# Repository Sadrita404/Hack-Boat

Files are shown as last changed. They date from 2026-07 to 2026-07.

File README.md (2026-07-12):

<div align="center">
  <table border="0" cellpadding="0" cellspacing="0">
    <tr>
      <td align="center" style="background: #ffffff; border: 1px solid #d0d7de; border-radius: 12px; padding: 16px; box-shadow: 0 4px 12px rgba(0,0,0,0.05);">
        Rough Layout For The PCB
        <div style="margin-top: 12px; font-family: -apple-system, BlinkMacSystemFont, 'Segoe UI', Helvetica, Arial, sans-serif; font-size: 13px; color: #57606a; font-weight: 500;">
      </td>
    </tr>
  </table>
</div>

|Title | Hack Boat |
|:-- |:--|
|Author | Sadrita Neogi|

## Overview
It is an open source Hack Boat it is fully 3d Printed and it has a water cooled motor with custom rudder for boat movement it uses 6 channel transmission to control the boat also it is fully covered with carbon - fiber on the inside body

## Why I choose this project?

So behind choosing this project for a very long time, I was fascinated with this RC board since how the working principal like when I got to know about 3D printing. Then from now, I have been planning to build one for myself which I can 3-D print and it would be much more economical so for that I have made this

##  How to use this project
This project mainly is an hobby purpose project, but we can use it to feed fish or perform small rescue missions like for small project. It can send GPS tracking data from the pond with the  Attach water quality monitor to the boat and check the water Quality of the pond.

## Features
* Fully 3d Printed Body
* Water Cooled Motor
* Long Range Transmission
* Custom Water Quality Monitoring System
* Has 6 Channel transmitter
* Carbon Fiber Inside
* Fully Open Source

## General Schematic

Wiring diagram

|  |  | Building Process |  |  |
| :-: | :-: | :-: | :-: | :-: |
| Building Process 1 | Building Process 3 | Building Process 4 | Building Process 5 | Building Process 6 |
| Building Process 9 | Building Process 11 | Building Process 14 | Building Process 16 | Building Process 20 |
| Building Process 23 | Building Process 25 | Building Process 26 | Building Process 27 | Building Process 30 |
| Building Process 34 | Building Process 35 | Building Process 37 | Building Process 39 | Building Process 40 |
| Building Process 1 | Building Process 2 | Building Process 3 | Building Process 4 | Building Process 5 |  |

<div align="center">
  <h2> PCB Final (Water Quality Monitor) </h2>
  <table border="0" cellpadding="10" cellspacing="0" style="border-collapse: collapse;">
    <tr>
      <!-- FRONT SIDE CARD -->
      <td align="center" valign="top" width="50%" style="background: #ffffff; border: 1px solid #d0d7de; border-radius: 12px; padding: 16px; box-shadow: 0 4px 12px rgba(0,0,0,0.05);">
        Front Side View
        <div style="margin-top: 12px; font-family: -apple-system, BlinkMacSystemFont, 'Segoe UI', Helvetica, Arial, sans-serif; font-size: 13px; color: #57606a; font-weight: 600; text-transform: uppercase; letter-spacing: 0.5px;">
          ▲ Front Side View
        </div>
      </td>
      <!-- SPACER FOR GITHUB MOBILE DEGRADATION -->
      <td width="2%">&nbsp;</td>
      <!-- BACK SIDE CARD -->
      <td align="center" valign="top" width="50%" style="background: #ffffff; border: 1px solid #d0d7de; border-radius: 12px; padding: 16px; box-shadow: 0 4px 12px rgba(0,0,0,0.05);">
        Back Side View
        <div style="margin-top: 12px; font-family: -apple-system, BlinkMacSystemFont, 'Segoe UI', Helvetica, Arial, sans-serif; font-size: 13px; color: #57606a; font-weight: 600; text-transform: uppercase; letter-spacing: 0.5px;">
          ▲ Back Side View
        </div>
      </td>
    </tr>
  </table>
</div>
</div>

## Fusion Renders 

<div align="center">

Render 1
Render 2
Render 3
Render 4
Render 5
Render 6
Render 7

</div>

<div align="center">
  <h2> Bill of Materials</h2>
</div>

Here is your complete data formatted cleanly as a Markdown table, matching your requested format exactly:

| Name | Purpose | Quantity | Total Cost (USD) | Link | Distributor |
| --- | --- | --- | --- | --- | --- |
| Rocket 3670 brushless rc boat motor | The Main Motor | 1 | 36 | [Link](https://robu.in/product/rocket-3670-brushless-rc-boat-motor-4pole-%ef%bf%a05-0mm-black-1550-kv/) | Robu |
| Water Cooling Jacket for RC Boat Brushless Motor | To cool the motor from overheating | 1 | 13 | [Link](https://www.amazon.in/MERISHOPP-2xMetal-Brushless-Educational-Learning/dp/B0FQCK9XJG) | Amazon |
| 80A Bidirectional Water-Cooled ESC 2-6S | To run the Motor | 1 | 28 | [Link](https://evelta.com/50a-60a-80a-bidirectional-water-cooled-esc-2-6s-ubec-5a-5v-for-rc-ship-underwater-propeller/?sku=447-E-125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) | Evelta |
| RC Boat Rudder with Absoring Water Pickup | For the Boat Movement | 1 | 13 | [Link](https://www.amazon.in/SNAPPSY%C2%AE-Control-Absoring-Vehicle-Accessories/dp/B0GF7ZSJV9) | Amazon |
| RC Ship Drive Shaft+Motor Coupler | For the Boat Movement | 1 | 17 | [Link](https://www.amazon.in/Enakshi%C2%AE-Coupler-Propeller-Hobbies-Vehicle/dp/B0FR44DW2N) | Amazon |
| RC Boat Flex Shaft Prop | For the Boat Movement | 1 | 20 | [Link](https://www.amazon.in/ZDingTech-UDI005-09-UDI005-Upgrade-Propellers/dp/B0CDL9DS27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) | Amazon |
| Pro- Range 22.2V 4200mAh 35C 6S Lithium Polymer Battery | To power the whole circuit(this need for the motor to run at least for 15mins) | 1 | 59.2 | [Link](https://robu.in/product/orange-4200mah-6s-40c80c-lithium-polymer-battery-pack-lipo/) | Robu |
| Digital Waterproof 20KG 270 Degree DC Servo | For Rudder Movement | 1 | 22 | [Link](https://robu.in/product/digital-waterproof-20kg-270-degree-dc-servo/) | Robu |
| IMAX B6 80W 6A Charger/Discharger | To charge the battery | 1 | 19.1 | [Link](https://robu.in/product/imax-b6-80w-6a-charger-discharger-1-6-cells/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) | Robu |
| CT-8A Transmitter+F-08A Receiver(PWM) | To Control the boat | 1 | 34 | [Link](https://robu.in/product/ct-8a-transmitterf-08a-receiverpwm/) | Robu |
| Silicon Carbide Scratch Filler Putty Grey | To hide the layer lines of the 3d Print and to make the surface smooth | 1 | 3 | [Link](https://www.amazon.in/VAI-Silicon-Carbide-Sandpaper-Scratches/dp/B0DRT95YYG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) | Amazon |
| Epoxy Resin and Hardener | To make the boat water proof | 1 | 2.99 | [Link](https://www.amazon.in/DYNAMIC-EDGE-Hardener-Long-Lasting-Non-Toxic/dp/B0CWZ8G5CM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) | Amazon |
| Carbon Fiber Fabric 30x100cm | To make the frame strong | 1 | 10.5 | [Link](https://www.amazon.in/carbonblack-composites-genuine-carbon-fabric/dp/B07QF46HPG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) | Amazon |
| Clear Coat | To make the paint stay at the body | 1 | 2.2 | [Link](https://www.amazon.in/Nippon-Paint-Pylac-Spray-RS-Clear/dp/B01GKBXW2A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) | Amazon |
| Spray Paint Colour | For the boat | 1 | 2.2 | [Link](https://www.amazon.in/Asian-Paints-ezyCR8-Apcolite-Spray/dp/B0FK4SN4KF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) | Amazon |
| PCB(moq5)| For the water quality Monitor | 5 | 4| [JLCPCB](https://jlcpcb.com/)| JLCPCB |
| Tax |  |  | 3.3 |  |  |
| Shipping Charges | incl PCB |  | 14.2 |  |  |
| Total |  |  | 303 |  |  |
| Round Off Total | Dollar rate fluctuation |  | 310 |  |  |

## Copyright and License
Copyright (c) 2026 Sadrita Neogi. All rights reserved.

All files are licensed under the MIT license. For more information, see the [LICENSE](LICENSE).

Project Under Hack Club

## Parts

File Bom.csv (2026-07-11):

Name | Purpose | Quantity | Total Cost (USD) | Link | Distributor
Rocket 3670 brushless rc boat motor | The Main Motor | 1 | 36 | https://robu.in/product/rocket-3670-brushless-rc-boat-motor-4pole-%ef%bf%a05-0mm-black-1550-kv/ | Robu
Water Cooling Jacket for RC Boat Brushless Motor | To cool the motor from overheating | 1 | 13 | https://www.amazon.in/MERISHOPP-2xMetal-Brushless-Educational-Learning/dp/B0FQCK9XJG | Amazon
80A Bidirectional Water-Cooled ESC 2-6S | To run the Motor | 1 | 28 | https://evelta.com/50a-60a-80a-bidirectional-water-cooled-esc-2-6s-ubec-5a-5v-for-rc-ship-underwater-propeller/?sku=447-E-125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 | Evelta
RC Boat Rudder with Absoring Water Pickup | For the Boat Movement | 1 | 13 | https://www.amazon.in/SNAPPSY%C2%AE-Control-Absoring-Vehicle-Accessories/dp/B0GF7ZSJV9 | Amazon
RC Ship Drive Shaft+Motor Coupler | For the Boat Movement | 1 | 17 | https://www.amazon.in/Enakshi%C2%AE-Coupler-Propeller-Hobbies-Vehicle/dp/B0FR44DW2N | Amazon
RC Boat Flex Shaft Prop | For the Boat Movement | 1 | 20 | https://www.amazon.in/ZDingTech-UDI005-09-UDI005-Upgrade-Propellers/dp/B0CDL9DS27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 | Amazon
Pro- Range 22.2V 4200mAh 35C 6S Lithium Polymer Battery | To power the whole circuit | 1 | 59.2 | https://robu.in/product/orange-4200mah-6s-40c80c-lithium-polymer-battery-pack-lipo/ | Robu
Digital Waterproof 20KG 270 Degree DC Servo | For Rudder Movement | 1 | 22 | https://robu.in/product/digital-waterproof-20kg-270-degree-dc-servo/ | Robu
IMAX B6 80W 6A Charger/Discharger | To charge the battery | 1 | 19.1 | https://robu.in/product/imax-b6-80w-6a-charger-discharger-1-6-cells/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 | Robu
CT-8A Transmitter+F-08A Receiver(PWM) | To Control the boat | 1 | 34 | https://robu.in/product/ct-8a-transmitterf-08a-receiverpwm/ | Robu
Silicon Carbide Scratch Filler Putty Grey | To hide the layer lines of the 3d Print and to make the surface smooth | 1 | 3 | https://www.amazon.in/VAI-Silicon-Carbide-Sandpaper-Scratches/dp/B0DRT95YYG?adgrpid=198415552724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 | Amazon
Epoxy Resin and Hardener | To make the boat water proof | 1 | 2.99 | https://www.amazon.in/DYNAMIC-EDGE-Hardener-Long-Lasting-Non-Toxic/dp/B0CWZ8G5CM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 | Amazon
Carbon Fiber Fabric 30x100cm | To make the frame strong | 1 | 10.5 | https://www.amazon.in/carbonblack-composites-genuine-carbon-fabric/dp/B07QF46HPG | Amazon
Clear Coat | To make the paint stay at the body | 1 | 2.2 | https://www.amazon.in/Nippon-Paint-Pylac-Spray-RS-Clear/dp/B01GKBXW2A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 | Amazon
Spray Paint Colour | For the boat | 1 | 2.2 | https://www.amazon.in/Asian-Paints-ezyCR8-Apcolite-Spray/dp/B0FK4SN4KF?mcid=e4589ed26a5734c9afb790c57e249174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 | Amazon
PCB(moq5) | For the water quality monitor | 5 | 4 | https://jlcpcb.com/ | JLCPCB
Tax |  |  | 3.3
Shipping Charges | Incl. PCB |  | 14.2
Total |  |  | 303
Round Off Total | Dollar rate fluctuation | 310

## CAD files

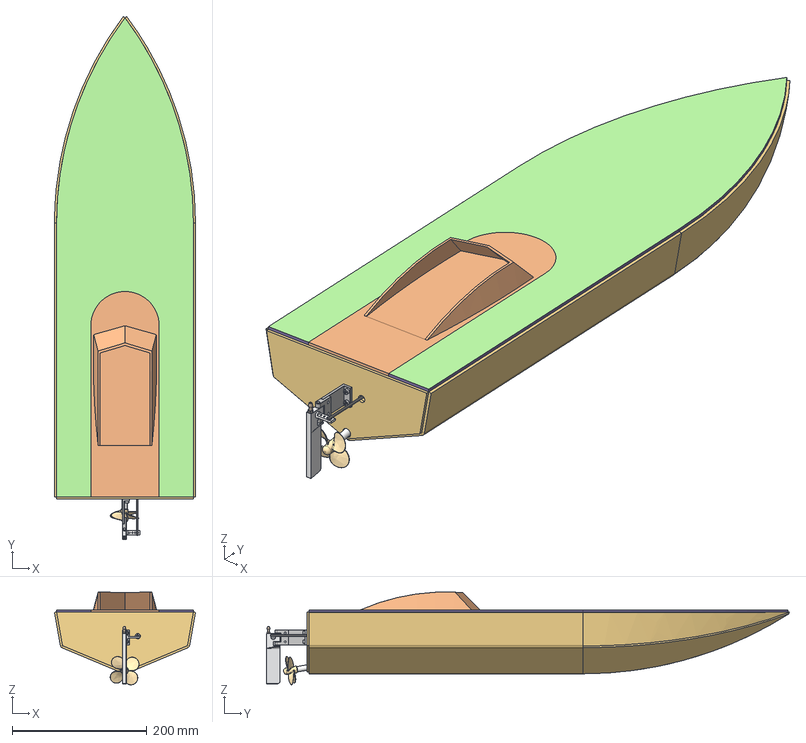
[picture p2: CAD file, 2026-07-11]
CAD/Hack Boat Assembly.step
209.5 x 776.4 x 137.7 mm
BateauVinh
PlancherBateauVinh
CokpitBateauVinh
BateauVinhPlateMotor
BateauVinhServoPlate
BS EN ISO 4762 - M3 x 16 Stainless Steel A4 Plain x 2
10000003170_000_SWP
10000003171_000_SWP
10000003172_000_SWP
100000116333_000_SWP_01
100000116172_000_SWP_5
10000011598_000_SWP
100000116172_000_SWP_4
100000115689_000_SWP

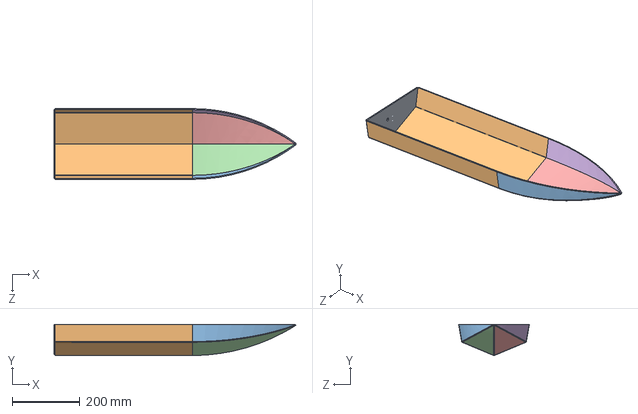
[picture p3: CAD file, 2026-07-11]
CAD/Base Case.STEP
716.3 x 92.0 x 209.5 mm

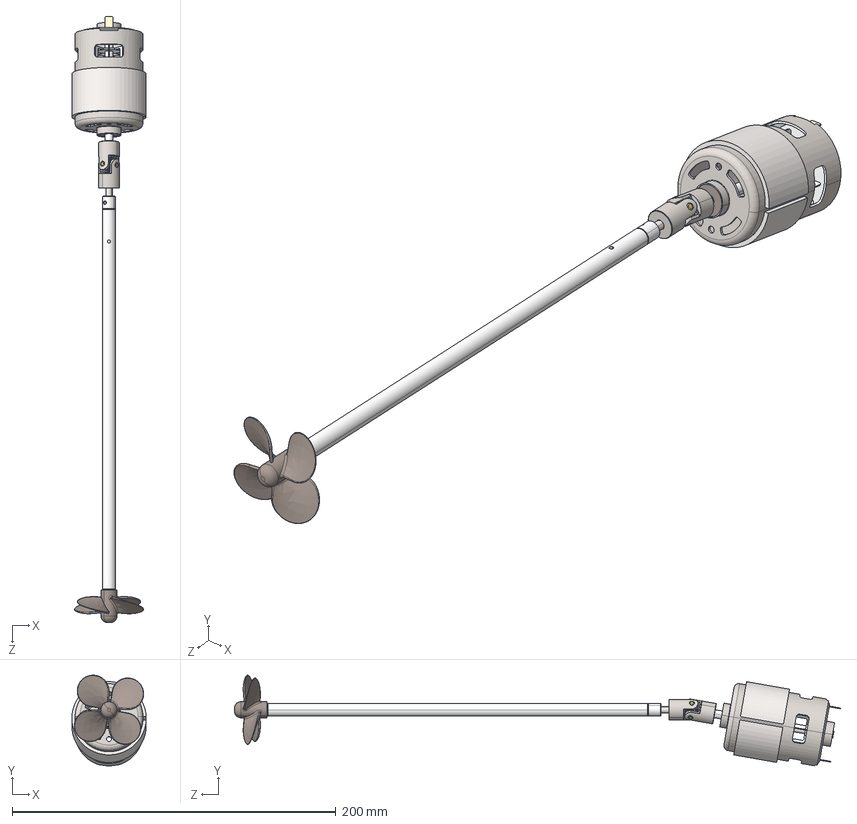
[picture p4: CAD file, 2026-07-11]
CAD/Propeller.STEP
46.0 x 56.1 x 374.6 mm
10000003170_000_SWP
10000003171_000_SWP
10000003172_000_SWP
100000116333_000_SWP_01
100000116172_000_SWP_�5
10000011598_000_SWP
100000116172_000_SWP_�4
100000115689_000_SWP

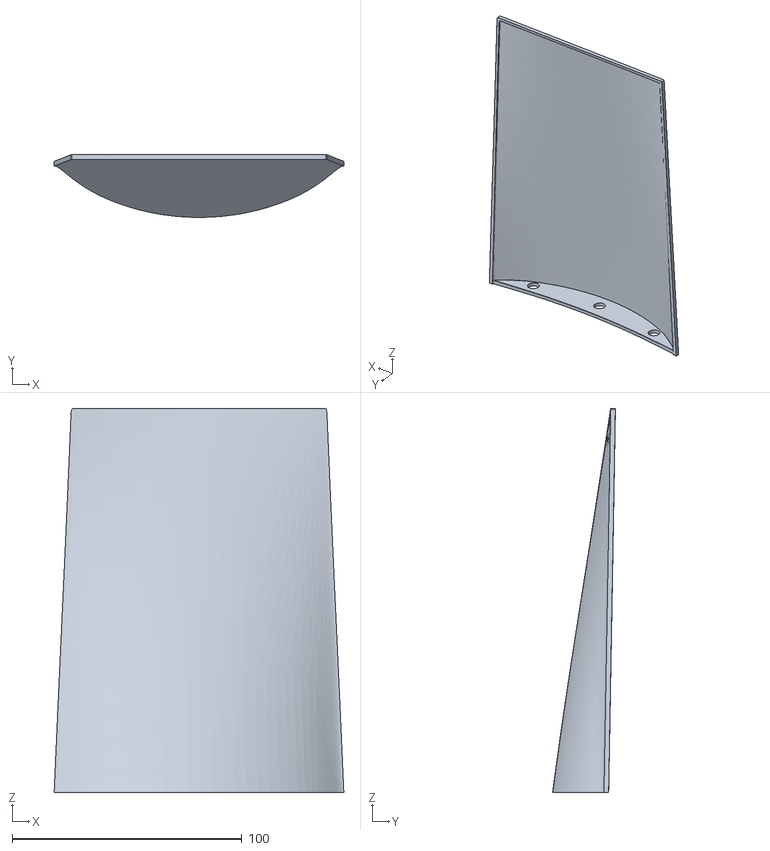
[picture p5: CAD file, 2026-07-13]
Hack Boat STL/[x1]case.stl
126.0 x 27.4 x 167.1

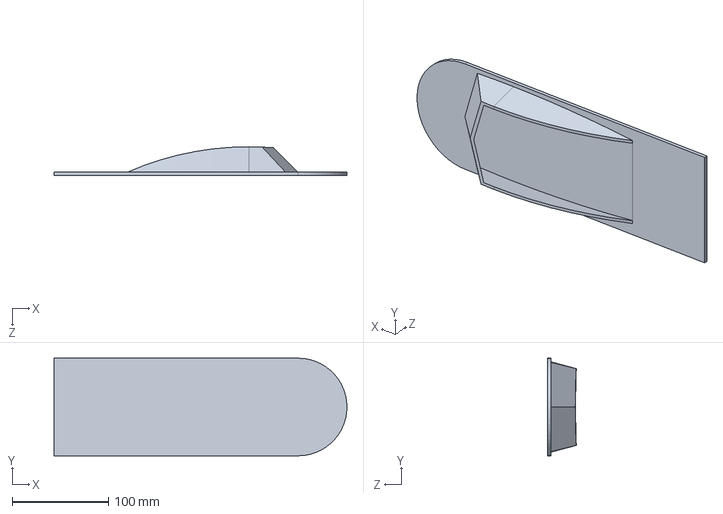
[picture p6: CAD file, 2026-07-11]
CAD/Top Cokpit Case.STEP
304.8 x 101.6 x 29.6 mm

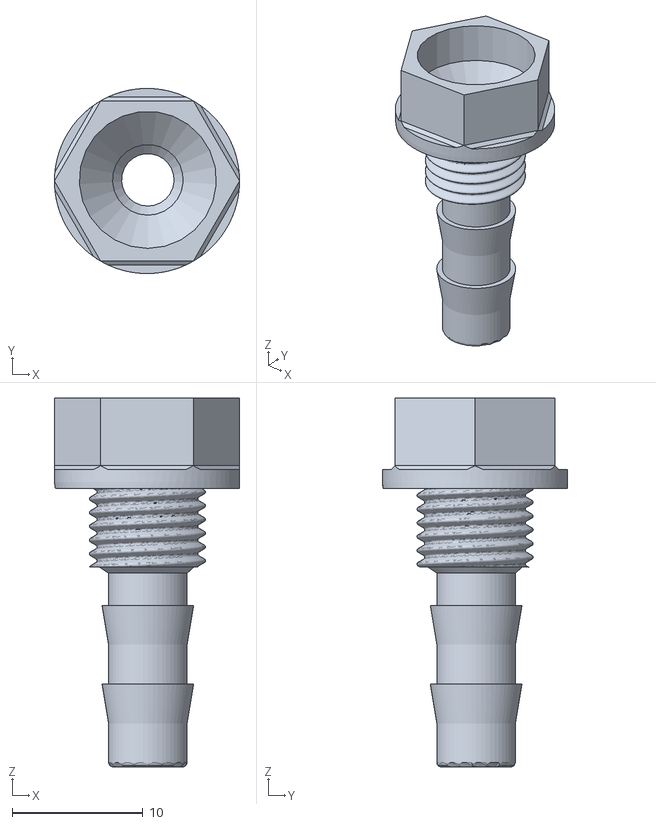
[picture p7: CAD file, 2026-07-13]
Hack Boat STL/[x2]Nozzle-6mm.stl
14.1 x 14.1 x 28.2

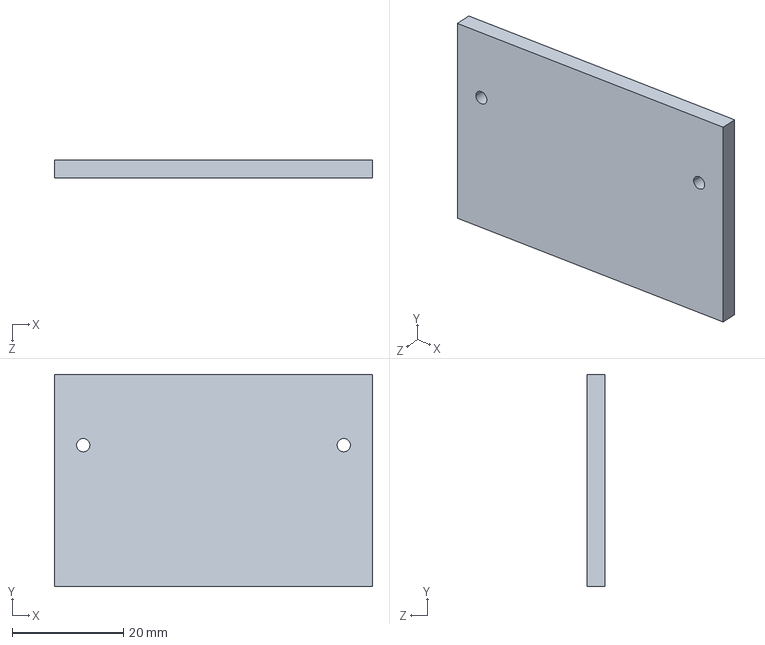
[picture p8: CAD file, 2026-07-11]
CAD/Servo mount Plate.STEP
57.1 x 38.1 x 3.17 mm

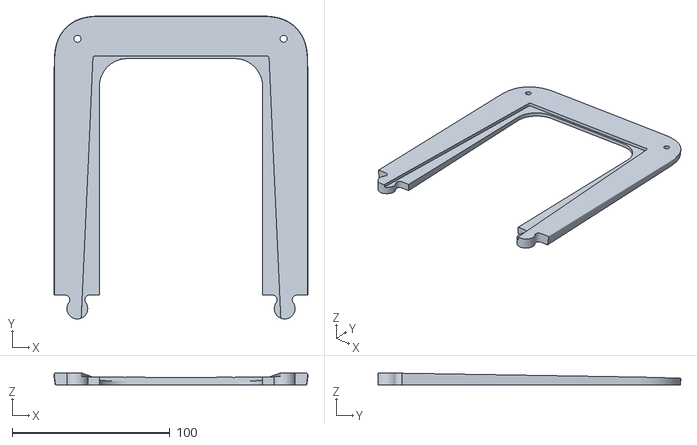
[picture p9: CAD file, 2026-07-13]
Hack Boat STL/[x1]lid top plate.stl
160.5 x 191.8 x 7.81

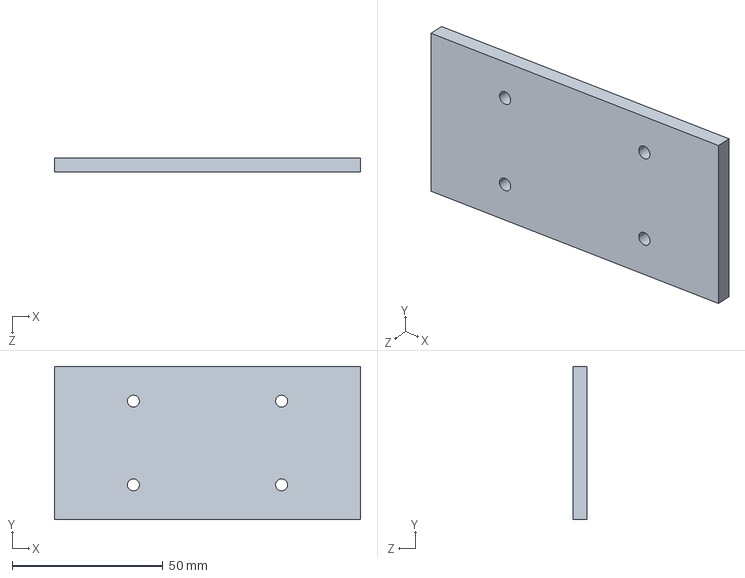
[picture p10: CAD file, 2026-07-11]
CAD/Motor mount Plate.STEP
101.6 x 50.8 x 4.76 mm

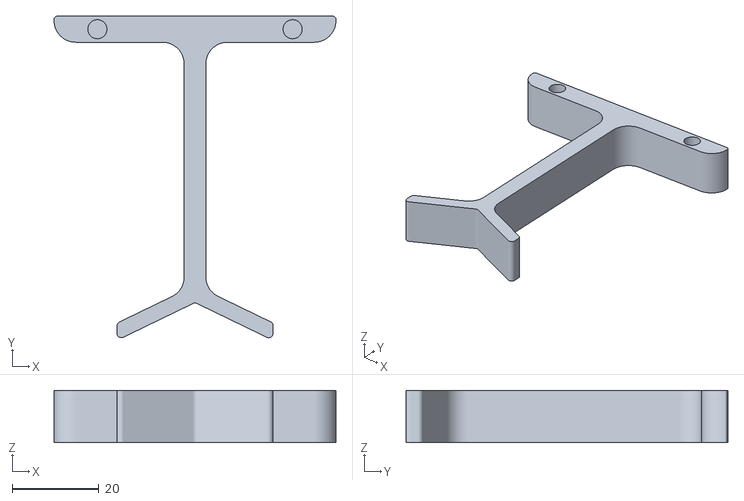
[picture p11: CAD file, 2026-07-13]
Hack Boat STL/[x2]stand.stl
65.0 x 74.1 x 12.0

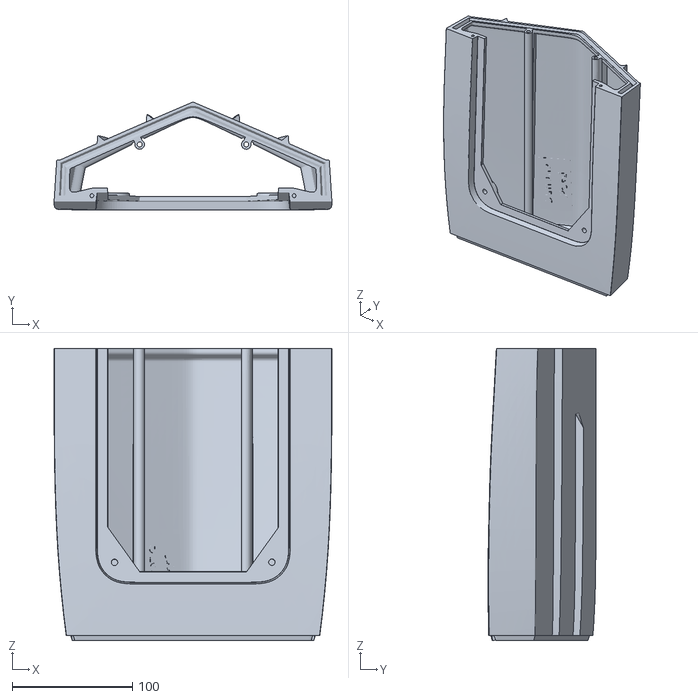
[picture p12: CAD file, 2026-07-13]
Hack Boat STL/[x1]bottom.stl
230.9 x 89.8 x 242.8

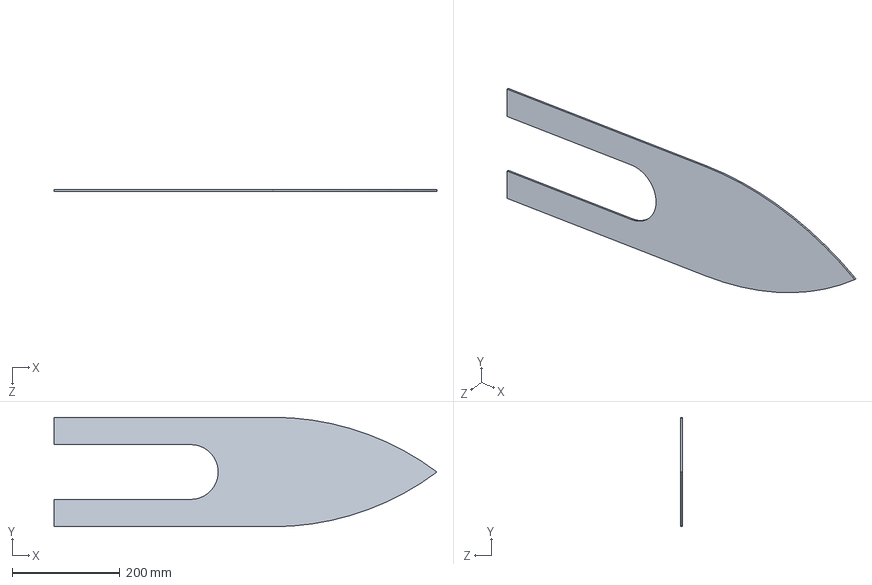
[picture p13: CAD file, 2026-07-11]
CAD/Top Cokpit Plate.STEP
711.2 x 203.2 x 3.17 mm

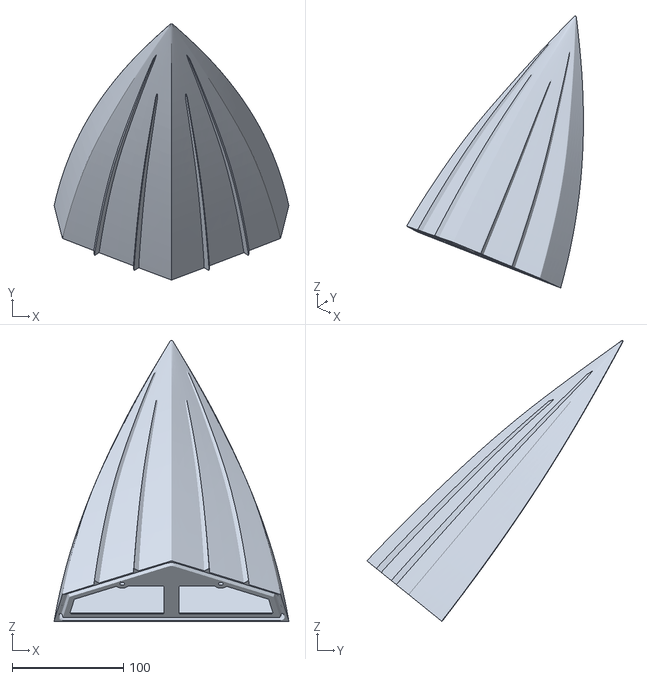
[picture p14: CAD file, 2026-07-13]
Hack Boat STL/[x1]nose.stl
210.9 x 230.1 x 252.4

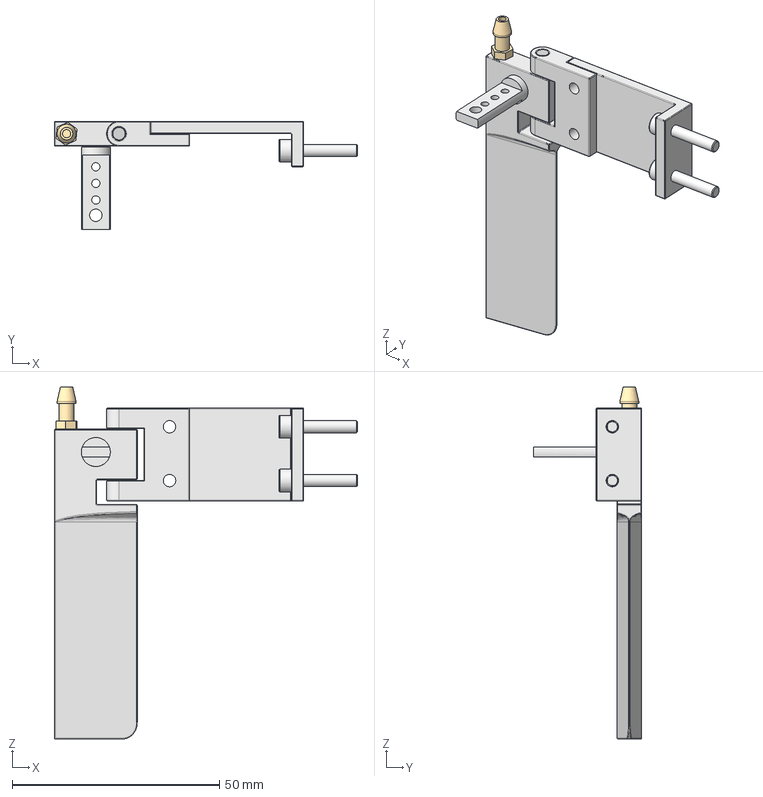
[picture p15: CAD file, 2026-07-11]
CAD/Boat Rudder.step
73.2 x 26.2 x 85.0 mm
BS EN ISO 4762 - M3 x 16 Stainless Steel A4 Plain x 2

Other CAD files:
Hack Boat STL/[x1]back chamber.stl
Hack Boat STL/[x1]top coover.stl
Hack Boat STL/[x1]lid.stl
Hack Boat STL/[x2]nozzle-screw.stl

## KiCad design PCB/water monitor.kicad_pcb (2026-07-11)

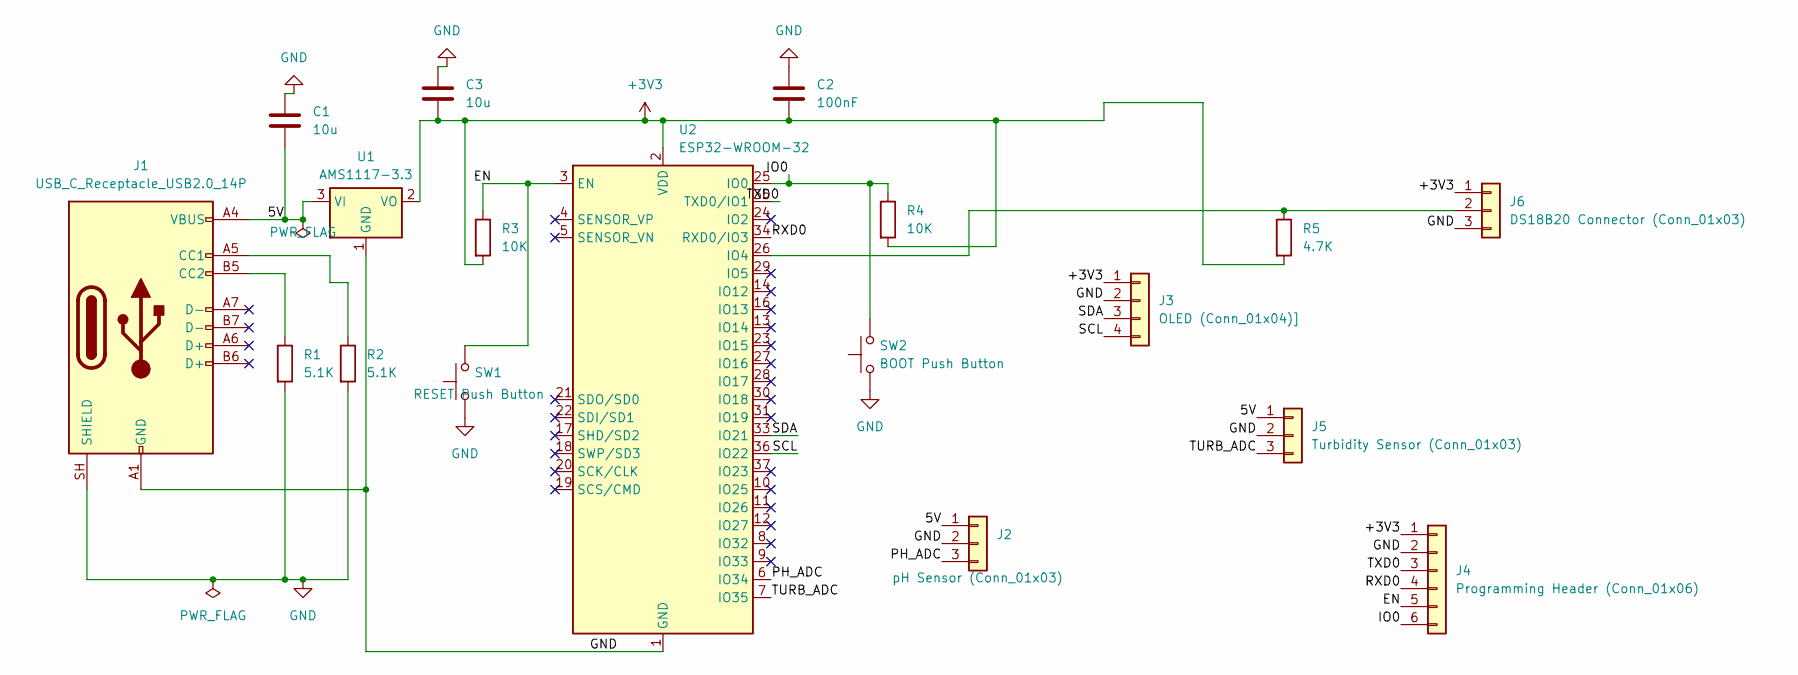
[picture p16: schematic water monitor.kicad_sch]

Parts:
C1, C3: 10u; C_0805_2012Metric
C2: 100nF; C_0805_2012Metric
J1: USB_C_Receptacle_USB2.0_14P; USB_C_Receptacle_GCT_USB4105-xx-A_16P_TopMnt_Horizontal
J2: pH Sensor (Conn_01x03); PinHeader_1x03_P2.54mm_Vertical
J3: OLED (Conn_01x04)]; PinHeader_1x04_P2.54mm_Vertical
J4: Programming Header (Conn_01x06); PinHeader_1x06_P2.54mm_Vertical
J5: Turbidity Sensor (Conn_01x03); PinHeader_1x03_P2.54mm_Vertical
J6: DS18B20 Connector (Conn_01x03); PinHeader_1x03_P2.54mm_Vertical
R1, R2: 5.1K; R_0805_2012Metric
R3, R4: 10K; R_0805_2012Metric
R5: 4.7K; R_0805_2012Metric
SW1: RESET Push Button; SW_PUSH_6mm
SW2: BOOT Push Button; SW_PUSH_6mm
U1: AMS1117-3.3; SOT-223-3_TabPin2
U2: ESP32-WROOM-32

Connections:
+3V3: C2.2, C3.2, J3.1, J4.1, J6.1, R3.2, R4.2, R5.2, U1.2 (VO), U2.2 (VDD)
/5V: C1.2, J1.A4 (VBUS), J1.A9 (VBUS), J1.B4 (VBUS), J1.B9 (VBUS), J2.1, J5.1, U1.3 (VI)
/EN: J4.5, R3.1, SW1.2, U2.3 (EN)
/IO0: J4.6, R4.1, SW2.2, U2.25 (IO0)
/PH_ADC: J2.3, U2.6 (IO34)
/RXD0: J4.4, U2.34 (RXD0/IO3)
/SCL: J3.4, U2.36 (IO22)
/SDA: J3.3, U2.33 (IO21)
/TURB_ADC: J5.3, U2.7 (IO35)
/TXD0: J4.3, U2.35 (TXD0/IO1)
GND: C1.1, C2.1, C3.1, J1.A1 (GND), J1.A12 (GND), J1.B1 (GND), J1.B12 (GND), J1.SH (SHIELD), J2.2, J3.2, J4.2, J5.2, J6.3, R1.2, R2.2, SW1.1, SW2.1, U1.1 (GND), U2.1 (GND), U2.15 (GND), U2.38 (GND), U2.39 (GND)
unnamed: J1.A5 (CC1), R2.1
unnamed: J1.B5 (CC2), R1.1
unnamed: J6.2, R5.1, U2.26 (IO4)

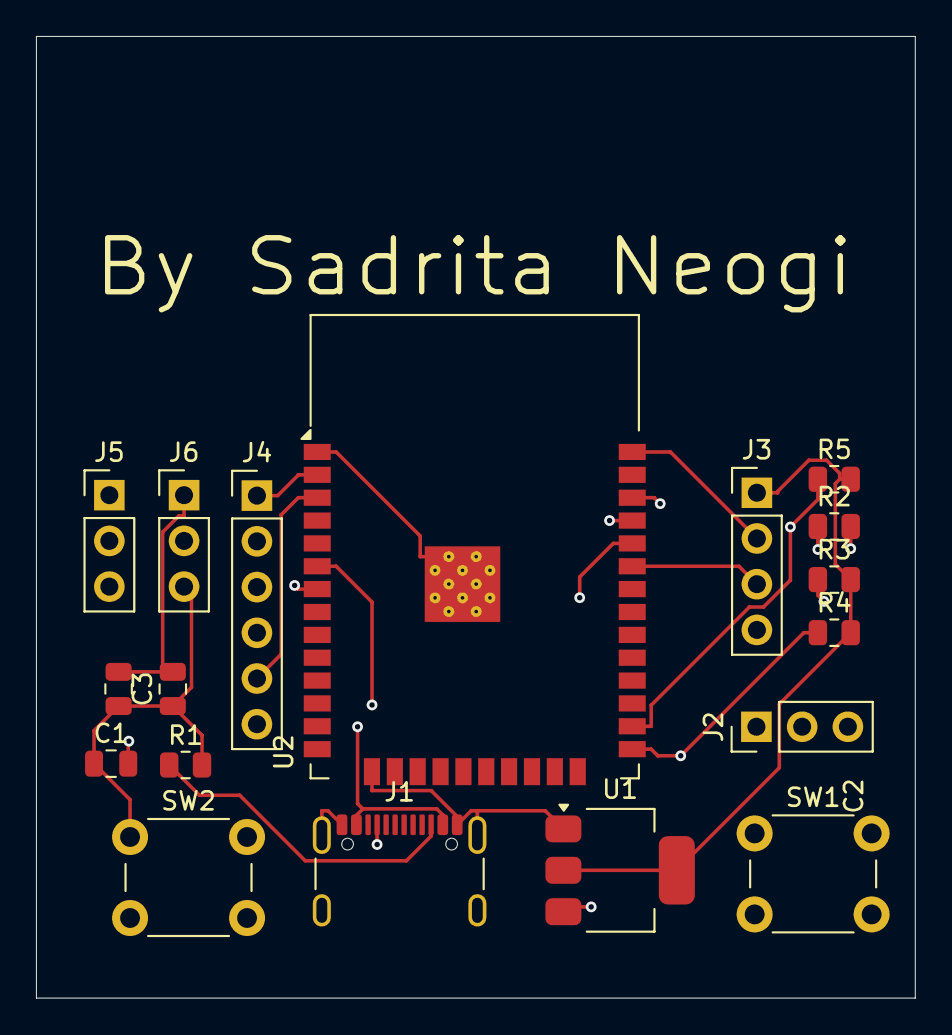
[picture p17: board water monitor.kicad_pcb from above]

Board: 4 copper layers, 48.8 x 53.4 mm, 18 parts (0 on the bottom side), 14 nets.

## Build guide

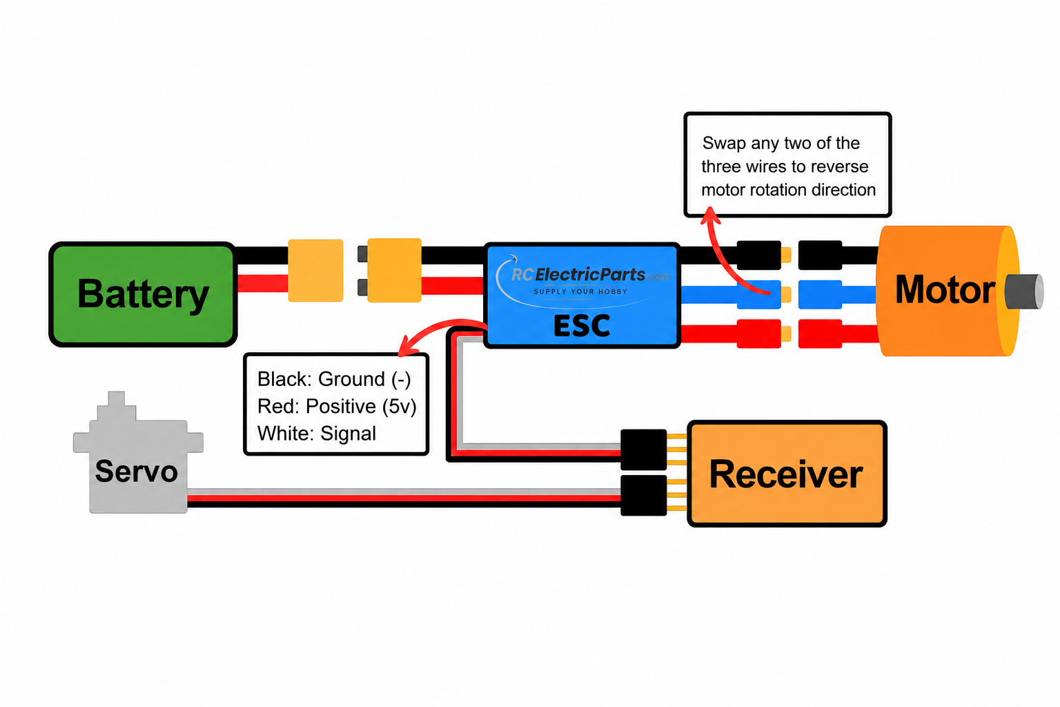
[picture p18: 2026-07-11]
Wiring Diagram/Wiring diagram.png

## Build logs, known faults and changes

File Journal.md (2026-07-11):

| Title | Hack Boat|
| :-- | :---|
|Author |Sadrita Neogi|
|Type | Hardware  |
Total Hrs | 18.1  |

# research about RC Boat and its design structure
So after deciding the project that I will build an RC boat, I went online to search for design model or the measurement dimension that I need to keep in mind while building it, so I dip into it and found out some key features that I need to think before making the CAD model..







_Total Time = 2hrs_

---
# Starting With the CAD

So after getting the design idea and the dimension, I wrote it down on a notebook. Then I started doing the cat mode according to the reference that I took from online and the inspo with it.
So for the first, I designed the top lid of the case for the base structure from where I can make the measurement changes so that I can now move onto the bottom part.




_Total Time = 0.6hrs_

---

# Making the nose of the boat 

So now, after completing with the top part of the boat, now from there, I took the measurement of the font, nose Path, and I am making one Way nose design and I have started making th CAD model for that I want to make it 3d Printable For that reason I am making into part wise .

**Inspo**





This took me lot of time as I was not familiar with this kind of design, so I need to watch a little bit tutorial and search online about how to design this kind of type side panel

_Total Time = 3.3hrs_

---

# Making the full Case

So After making the the front Nose of the Boat I went to add the top lid and the bottom part at one place so that I can make it together and move to the next part 




_Total Time = 0.4hrs_

---

# Maing the Rc Boat propeller with Motor and the connector 

Now I am working on the Rc Boat propeller for the boat which will be added with the motor and I have design mine for this as I am custom builiding it and no cad model is avilable for this build so I went to desing it bymy own and I keep the design simple but with correct dimensions .

**Making the axial Rod**






**Now the Coupler for the axial Rod and the Motor**






_Total Time = 2.2hrs_

---

# Now adding the Motor to the Boat (But not complete)

So after designing the Motor with the propeller Now I went to add that Model to the main assembly file of the project 





**While adding the motor to the boat, I found out that I need to 1st add the rudder to the model so that I can get the clearance to add the motor after that, so now I will make the rudder for the boat. Then I will add the motor.**

_Total Time = 0.2hrs_

---

# Making the Rudder for the Boat 

After I found out the problem, that first I need to made the Rudder for the Boat so now I am makign the Rudder for the boat in fusion 360 so that I can add it to the boat an next I can move to add the motor to it . and for the Rudder I made the tail custom for this boat ..










_Total Time = 2hrs_

---

# Now adding the  Rudder to the Boat 

After making the Rudder for the Boat now I move to add this to the main boat frame so that I can next add the motor and the propeller to it 






_Total Time = 0.4hrs_

---

# Now adding the Motor to the Boat (Final) and the servo shaft

 So now I have added the rider in the back of the boat. Now I can get the right dimension so that I can work on the motor and the propeller, and I have added it to the final assembly.





**servo shaft making**





_Total Time = 1.3hrs_

---

# Adding appearance to the final model






**Adding good metal texture to the rudder for the Render**



**Went for Hack Club Logo to add it in the Boat**


flag-standalone-bw

**adding the Hacl Club Logo to the Boat**




_Total Time = 1.1hrs_

# Making the Water Quality checker 

So my initial plan was to get an premade product, but later I found out then the custom bill was incomplete for that's why design and small. Simple water quality check so that I can put it into the boat and for that I have designed this and I have also made it using USB type C port for better connectivity

**First, I done with the schematic**

Screenshot 2026-07-12 at 2 38 53 AM

Screenshot 2026-07-12 at 2 39 08 AM

Screenshot 2026-07-12 at 2 39 27 AM

Screenshot 2026-07-12 at 2 39 32 AM

## DRC Check No error

Screenshot 2026-07-12 at 2 42 13 AM

Screenshot 2026-07-12 at 2 40 58 AM

Screenshot 2026-07-12 at 2 41 13 AM

_Total Time = 3.3hrs_

---

# Final Render in Fusion 360 

I actually like the final Render hopefully everyone also likes it ..
And it took a lot of time in the render as I need to creat the environment for each indiidual for each render and also it take a while to reender all the images.

Render 1
Render 2
Render 7

Render 3
Render 6

Render 4
Render 5

_Total Time = 1.3hrs_

---

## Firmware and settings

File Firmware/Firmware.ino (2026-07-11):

#include <Arduino.h>
#include <WiFi.h>
#include <AsyncTCP.h>
#include <ESPAsyncWebServer.h>
#include <Preferences.h>
#include <ArduinoJson.h>
#include <OneWire.h>
#include <DallasTemperature.h>


// --- Network Settings ---
const char* AP_SSID = "Pond-Water-Monitor-Pro";
const char* AP_PASS = "pond123456";
const char* ST_SSID = "YOUR_WIFI";      // Change to your home WiFi SSID if needed
const char* ST_PASS = "YOUR_PASSWORD";  // Change to your home WiFi Password

// --- Core Architecture Definitions ---
AsyncWebServer server(80);
AsyncWebSocket ws("/ws");
Preferences preferences;
OneWire oneWire(ONE_WIRE_BUS);
DallasTemperature sensors(&oneWire);

// FreeRTOS Task Handles
TaskHandle_t SensorTaskHandle = NULL;
TaskHandle_t TelemetryTaskHandle = NULL;
SemaphoreHandle_t dataMutex;

// --- Data Structures ---
struct WaterMetrics {
    float temperature = 25.0;
    float ph = 7.0;
    float tds = 0.0;
    float turbidity = 0.0;
    unsigned long timestamp = 0;
};

struct CalibrationData {
    float ph_4_voltage;
    float ph_7_voltage;
    float tds_factor;
    float turbidity_offset;
    float temp_offset;
};

// Global Context Instantiations
WaterMetrics currentMetrics;
CalibrationData calibration;
bool isSystemCalibrated = false;

// --- Signal Conditioning & Filtering ---
// Sorts samples and calculates the average of the middle variance band to eliminate spike noise
float readFilteredAnalog(uint8_t pin, int totalSamples = 32) {
    int samples[totalSamples];
    
    // Acquire samples
    for (int i = 0; i < totalSamples; i++) {
        samples[i] = analogRead(pin);
        delayMicroseconds(80);
    }
    
    // Simple bubble sort
    for (int i = 0; i < totalSamples - 1; i++) {
        for (int j = i + 1; j < totalSamples; j++) {
            if (samples[i] > samples[j]) {
                int temp = samples[i];
                samples[i] = samples[j];
                samples[j] = temp;
            }
        }
    }
    
    // Discard upper and lower 25% of samples, average the middle 50%
    long sum = 0;
    int startSample = totalSamples / 4;
    int endSample = totalSamples - startSample;
    int sampleCount = endSample - startSample;
    
    for (int i = startSample; i < endSample; i++) {
        sum += samples[i];
    }
    
    return (float)sum / sampleCount;
}

// --- Non-Volatile Memory (NVM) Management ---
void loadCalibrationSettings() {
    preferences.begin("pond_cal_v2", false);
    calibration.ph_4_voltage = preferences.getFloat("ph4v", 3.05);
    calibration.ph_7_voltage = preferences.getFloat("ph7v", 2.50);
    calibration.tds_factor = preferences.getFloat("tdsf", 1.00);
    calibration.turbidity_offset = preferences.getFloat("turboff", 0.0);
    calibration.temp_offset = preferences.getFloat("tempoff", 0.0);
    isSystemCalibrated = preferences.getBool("is_cal", false);
    preferences.end();
    Serial.println("[SYSTEM] Calibration settings loaded successfully from NVM.");
}

void saveCalibrationSettings() {
    preferences.begin("pond_cal_v2", false);
    preferences.putFloat("ph4v", calibration.ph_4_voltage);
    preferences.putFloat("ph7v", calibration.ph_7_voltage);
    preferences.putFloat("tdsf", calibration.tds_factor);
    preferences.putFloat("turboff", calibration.turbidity_offset);
    preferences.putFloat("tempoff", calibration.temp_offset);
    preferences.putBool("is_cal", true);
    preferences.end();
    Serial.println("[SYSTEM] NV-Storage written with updated calibration metrics.");
}

void resetCalibrationSettings() {
    preferences.begin("pond_cal_v2", false);
    preferences.clear();
    preferences.end();
    loadCalibrationSettings();
    Serial.println("[SYSTEM] Factory reset execution complete on NV-Storage namespace.");
}

// --- WebSocket Core Engine ---
void notifyClients() {
    if (ws.count() == 0) return; // Optimize transmission if no active sessions exist

    JsonDocument doc;
    doc["event"] = "telemetry";
    
    if (xSemaphoreTake(dataMutex, pdMS_TO_TICKS(100)) == pdTRUE) {
        doc["temp"] = currentMetrics.temperature;
        doc["ph"] = currentMetrics.ph;
        doc["tds"] = currentMetrics.tds;
        doc["turb"] = currentMetrics.turbidity;
        doc["uptime"] = currentMetrics.timestamp;
        xSemaphoreGive(dataMutex);
    }
    
    String jsonOutput;
    serializeJson(doc, jsonOutput);
    ws.textAll(jsonOutput);
}

void handleWebSocketMessage(void *arg, uint8_t *data, size_t len) {
    AwsFrameInfo *info = (AwsFrameInfo*)arg;
    if (info->final && info->index == 0 && info->len == len && info->opcode == WS_TEXT) {
        JsonDocument doc;
        DeserializationError error = deserializeJson(doc, data, len);
        if (error) return;

        if (doc.containsKey("request") && doc["request"] == "ping") {
            ws.textAll("{\"event\":\"pong\"}");
        }
    }
}

void onWsEvent(AsyncWebSocket *server, AsyncWebSocketClient *client, AwsEventType type,
               void *arg, uint8_t *data, size_t len) {
    switch (type) {
        case WS_EVT_CONNECT:
            Serial.printf("[WEBSOCKET] ClientNormally I can help with things like this, but I don't seem to have access to that content. You can try again or ask me for something else.

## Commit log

2026-07-11 all added
    [Base Case.STEP, Boat Rudder.step, Bom.csv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]
2026-07-12 Clarify battery description in README
    Updated the description for the Pro- Range 22.2V 4200mAh battery to specify its runtime capability.
2026-07-13 print on 0.2mm layer, 6 walls, 80% infill
    [[x1]back chamber.stl, [x1]bottom.stl, [x1]case.stl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]
